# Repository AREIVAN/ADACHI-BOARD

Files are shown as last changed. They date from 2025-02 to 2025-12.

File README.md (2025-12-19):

# ADACHI-BOARD  
### Custom Embedded Control Board for Mini Sumo Robotics  
**ESP32-S3 | PCB Design | Motor Control | Embedded Systems**

---

## 📍 Overview

**ADACHI-BOARD** is a **custom-designed embedded control board** developed for **Mini Sumo robotic applications**, focused on **real-time control**, **compact PCB design**, and **competition-grade reliability**.

This project was created as part of my professional and academic development in **Robotics, Embedded Systems, and Industrial Electronics**, and it is intended to serve as both a **functional robotic platform** and a **technical portfolio project**.

---

## 🎯 Project Objectives

- Design a **compact and robust PCB** for competitive robotics
- Implement **reliable motor control** using discrete drivers
- Apply **best practices in embedded hardware design**
- Demonstrate skills in:
  - PCB design
  - Power regulation
  - Microcontroller integration
  - Robotics-oriented system architecture

---

## ⚙️ System Architecture

- **Main MCU:** ESP32-S3 Mini-1U  
- **Motor Control:** Dual DRV8871 DC motor drivers  
- **Sensors:** Support for up to 10 external sensors  
- **Actuators:** 2 servo outputs  
- **User Interface:** Hardware buttons for strategy selection  
- **Programming Interface:** TTL (UART)  

The board is designed to minimize latency and allow fast response times, which are critical in competitive robotics environments.

---

## 📐 Technical Specifications

| Feature | Description |
|---|---|
| Board Size | 60 mm × 30 mm |
| Max Input Voltage | 24 V |
| MCU | ESP32-S3 Mini-1U |
| Motor Drivers | DRV8871 |
| Voltage Regulation | 5 V / 3.3 V |
| LEDs | SK0605 2427 |
| Programming | UART (TTL) |
| Target Application | Mini Sumo Robot |

---

## 🔘 Hardware Controls

- **RESET** – Microcontroller reset  
- **BOOT** – Programming mode access  
- **STRATEGY 1** – Strategy selection input  
- **STRATEGY 2** – Strategy selection input  

These buttons allow strategy changes without reflashing firmware, improving usability during competitions or testing.

---

## 🧠 Design Considerations

- Compact footprint optimized for Mini Sumo chassis
- Separation of power and logic domains
- Component selection focused on availability and reliability
- Design prepared for iterative improvement and future expansion

---

## 📂 Repository Structure



*(Structure may evolve as the project progresses)*

---

## 🚧 Project Status

- ✔ PCB design completed  
- ✔ Component selection validated  
- 🔄 Firmware development in progress  
- 🔄 Testing and optimization phase  

---

## 🔮 Planned Improvements

- Encoder feedback integration
- Power efficiency optimization
- Enhanced firmware architecture
- Step-by-step replication documentation
- Optional telemetry and data logging

---

## 👨‍💻 About the Author

**Areivan**  
Industrial Robotics Engineering Student  
Industrial Maintenance Technician  

- Experience in embedded systems and PCB design  
- Background in industrial automation and maintenance  
- Focused on robotics, electronics, and applied engineering  

🔗 GitHub: https://github.com/AREIVAN

---

## 📜 License & Usage

This project is intended for **educational and experimental purposes**.  
You may reference or reuse the design with proper credit to the author.

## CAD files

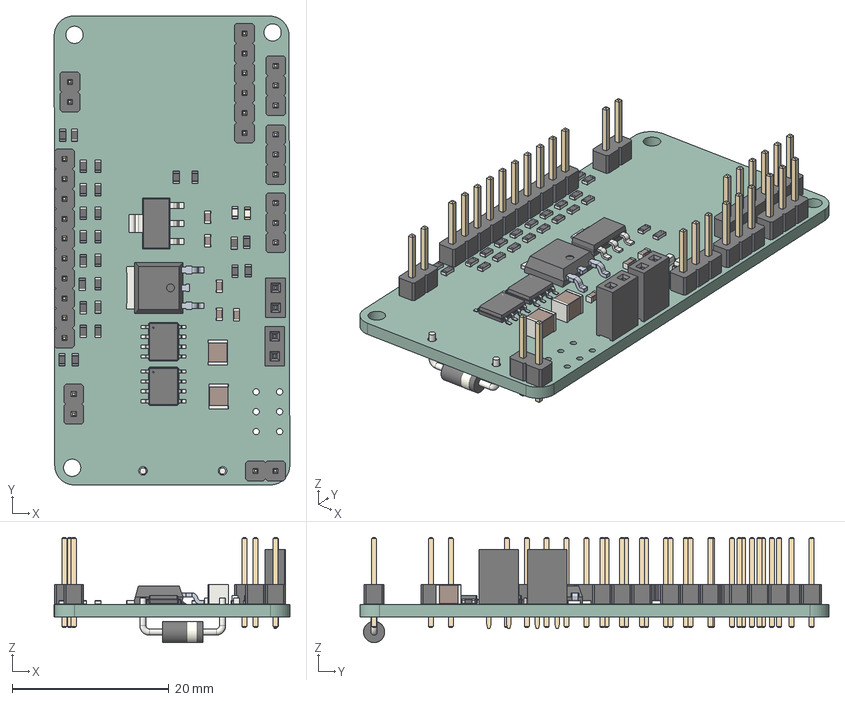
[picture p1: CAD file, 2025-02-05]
ADACHI/ADACHI.step
30.1 x 59.9 x 13.4 mm
PinHeader_1x06_P254mm_Vertical
R_0603_1608Metric x 26
C_0603_1608Metric x 5
PinHeader_1x02_P254mm_Vertical x 3
CQ assembly
PinHeader_1x03_P254mm_Vertical x 3
PinHeader_1x10_P254mm_Vertical
LED_0603_1608Metric x 2
C_1210_3225Metric x 2
PinSocket_1x02_P254mm_Vertical x 2
Texas_HTSOP_8_1EP_39x49mm_P127mm_EP285x49mm_Mask24x31mm_ThermalVias x 2
SOT_223
D_DO-41_SOD81_P10.16mm_Horizontal
ADACHI_PCB

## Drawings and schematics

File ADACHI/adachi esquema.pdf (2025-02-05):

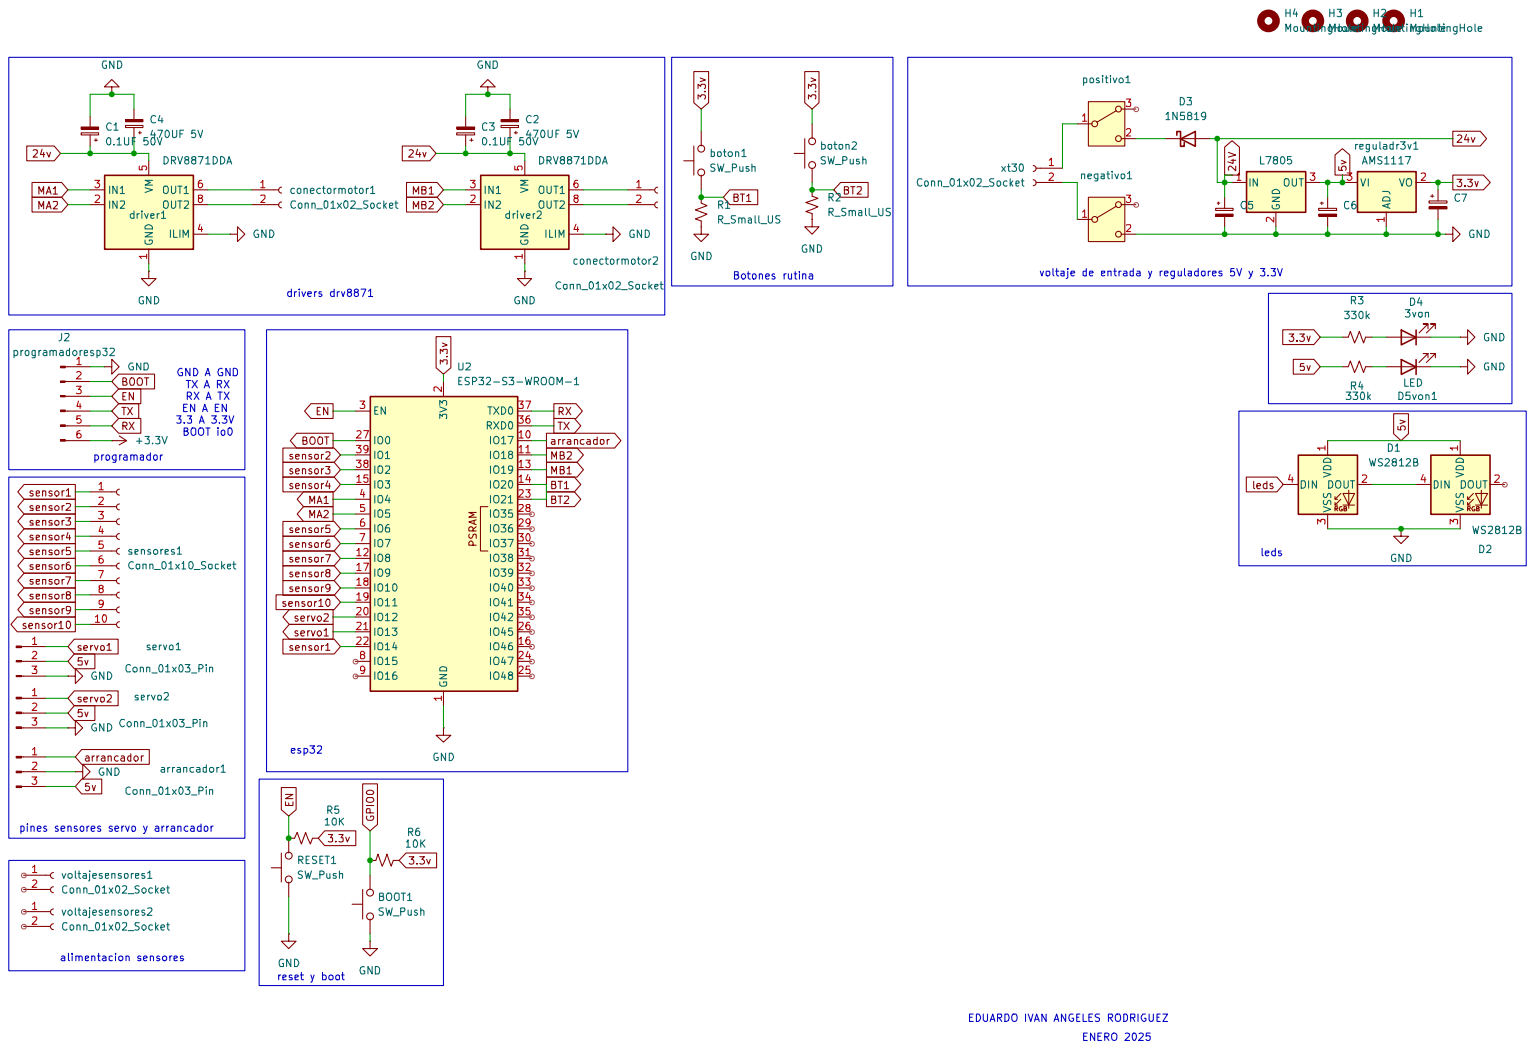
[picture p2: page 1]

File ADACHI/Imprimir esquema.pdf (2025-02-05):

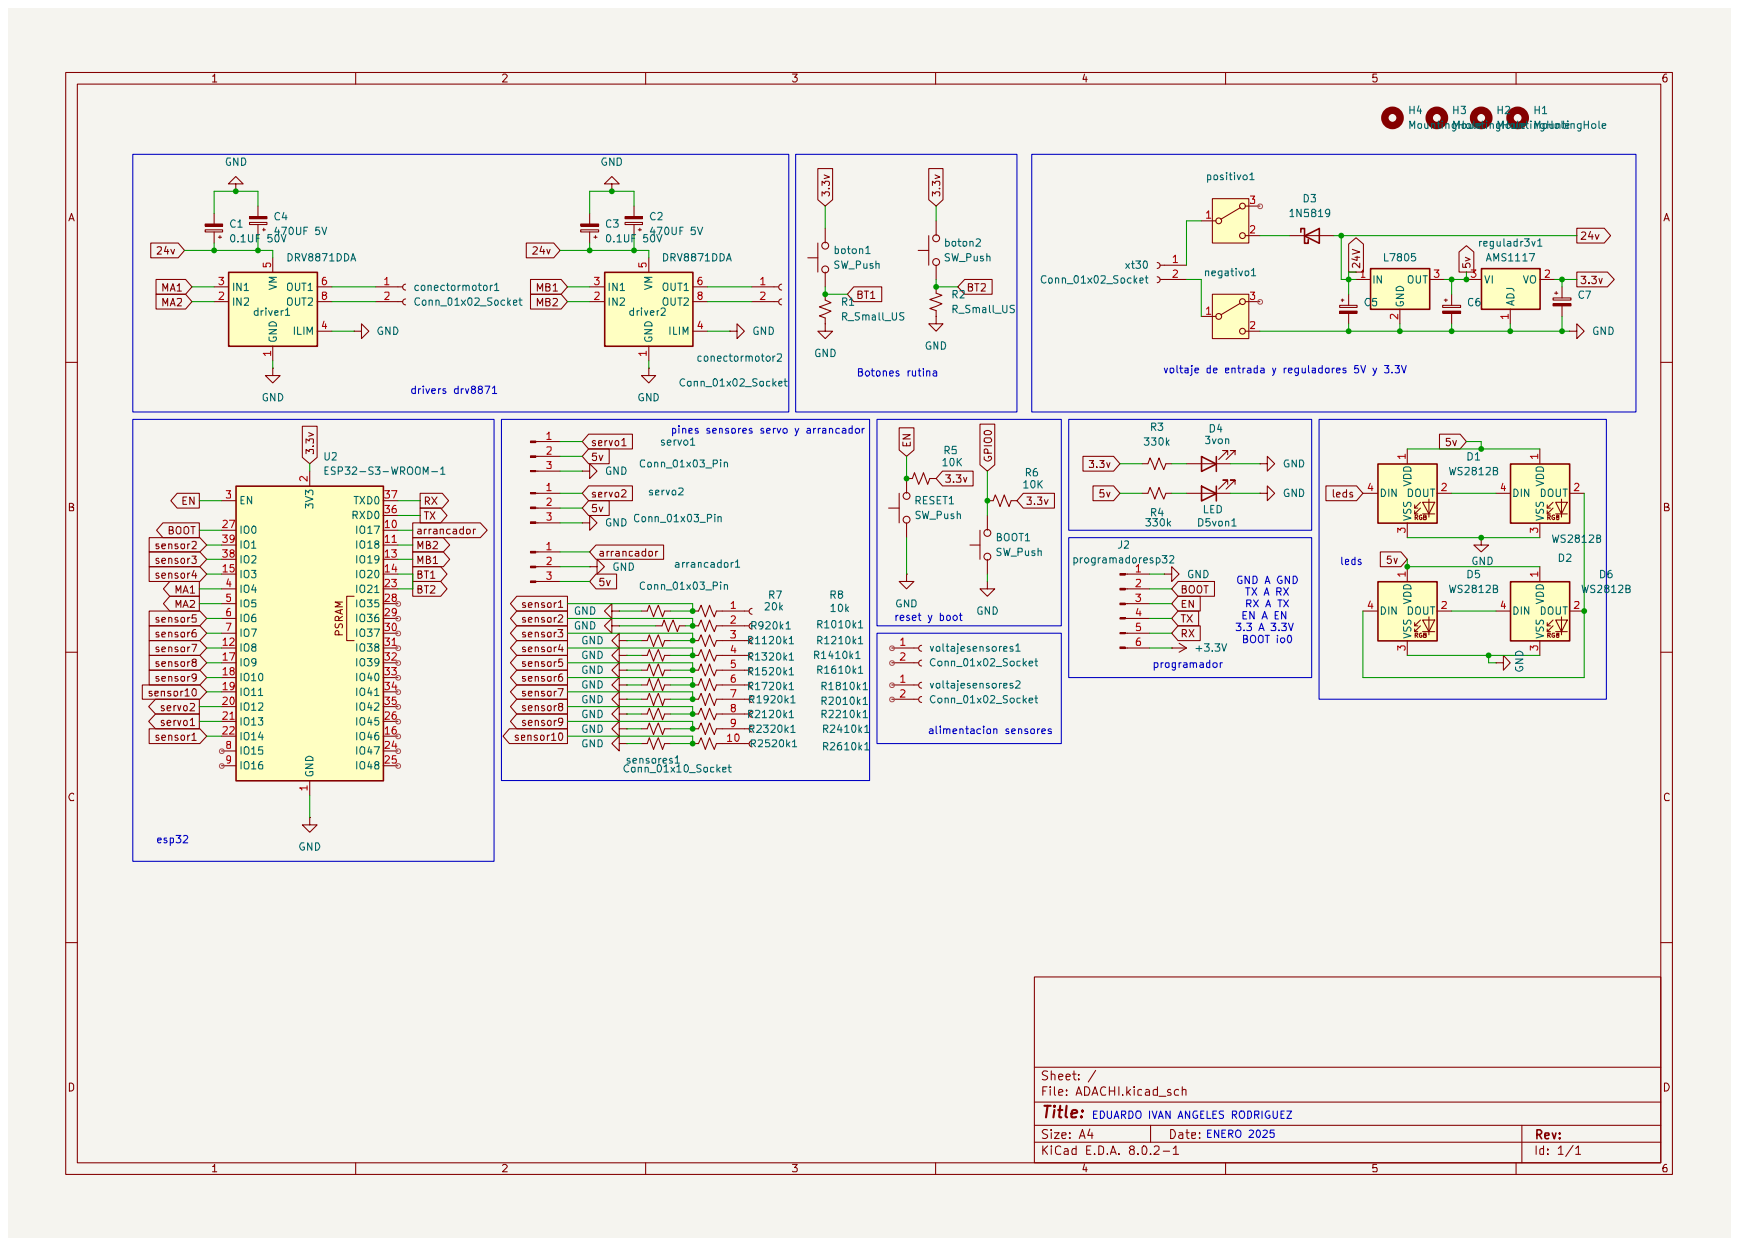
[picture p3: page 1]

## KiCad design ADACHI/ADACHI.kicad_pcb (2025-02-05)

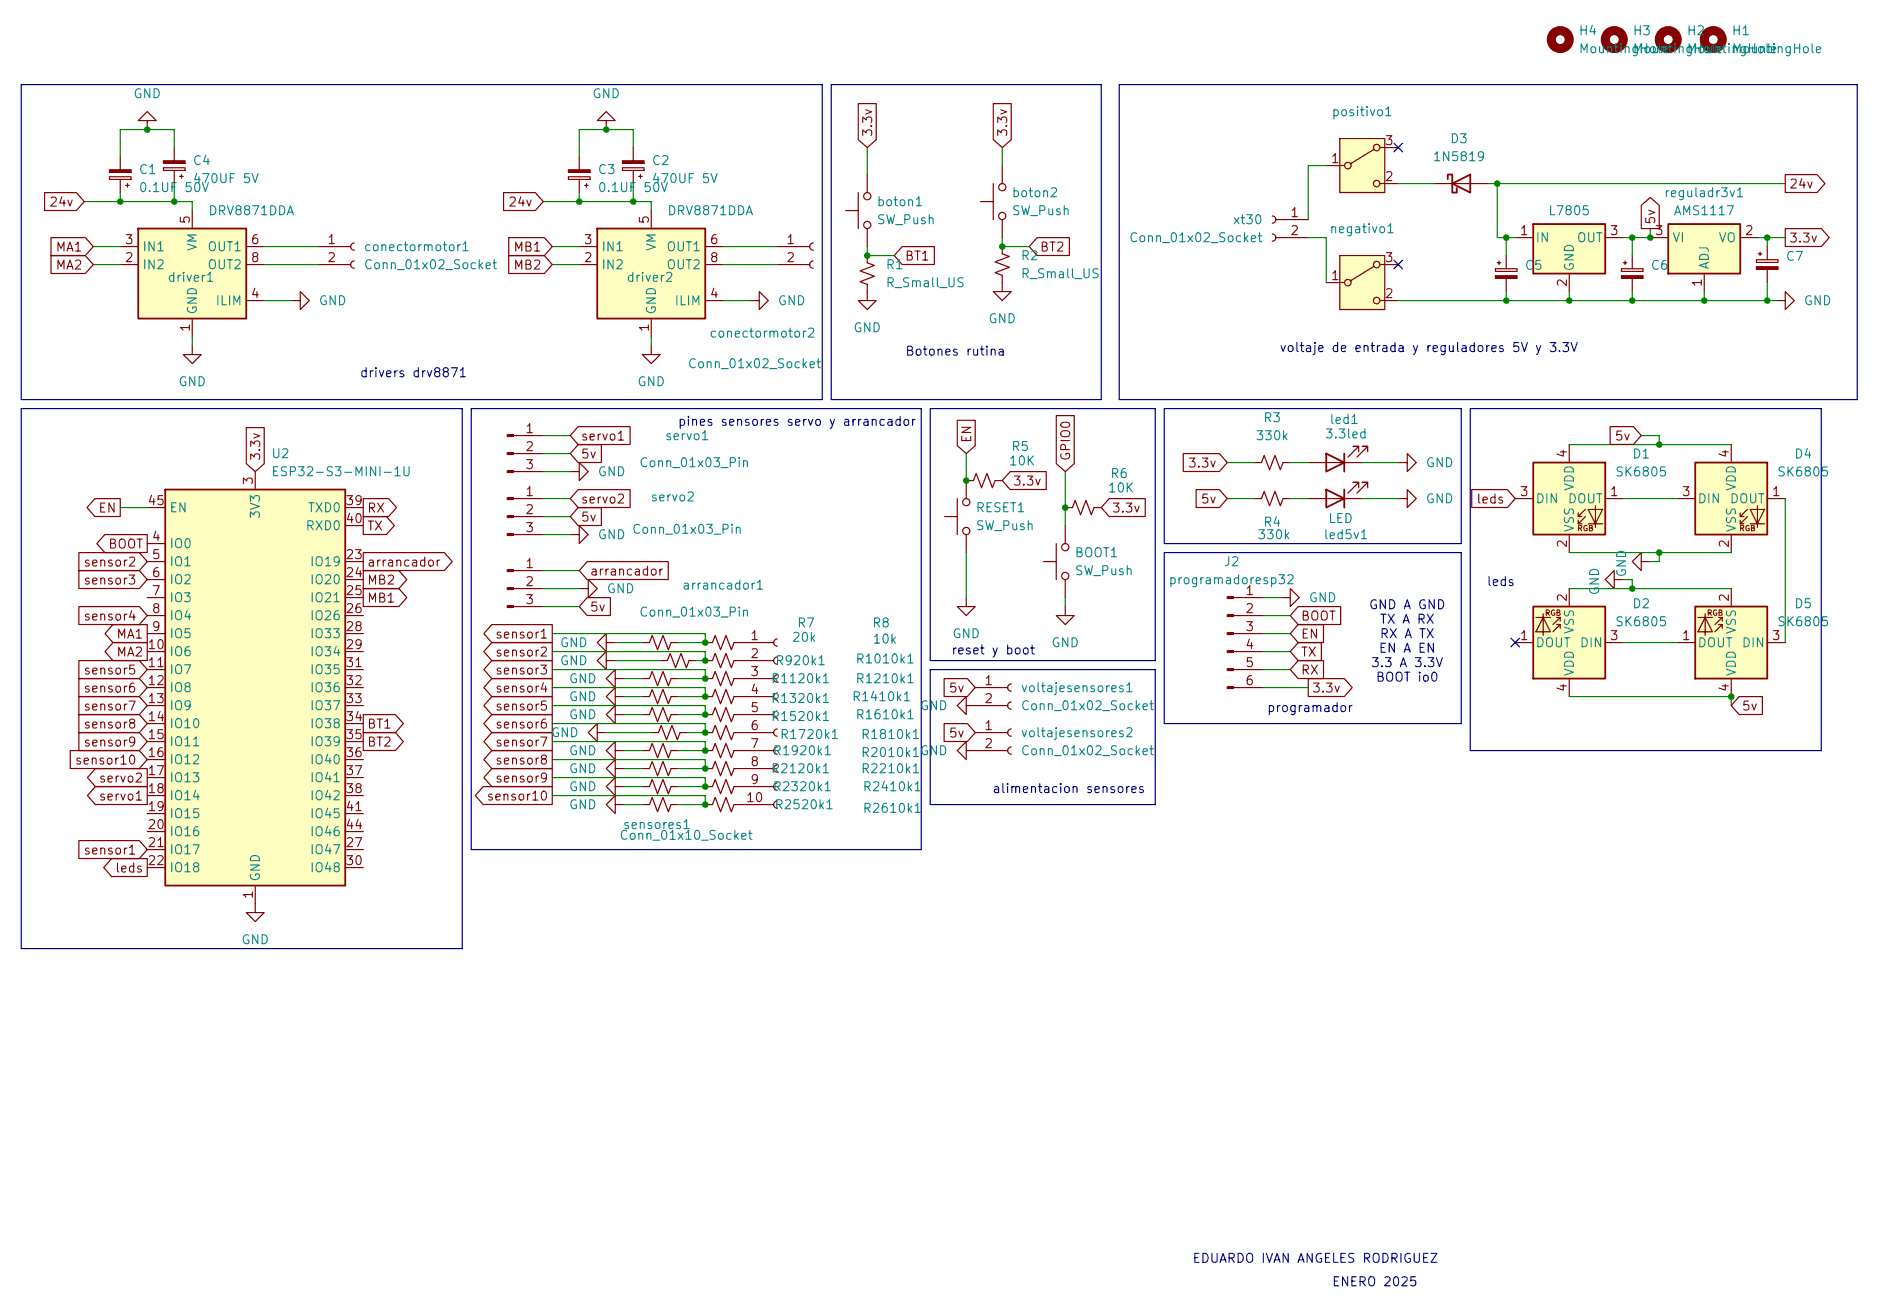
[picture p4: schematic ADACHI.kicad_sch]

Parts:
BOOT1: SW_Push; SW_Push_1P1T_NO_Vertical_Wuerth_434133025816
C1, C3: 0.1UF 50V; C_0603_1608Metric
C2, C4: 470UF 5V; C_1210_3225Metric
C5, C6, C7: C_0603_1608Metric
D1, D2, D4, D5: SK6805; LED_SK6805_PLCC4_2.4x2.7mm_P1.3mm
D3: 1N5819; D_DO-41_SOD81_P10.16mm_Horizontal
H1, H3, H4: MountingHole; MountingHole_2.2mm_M2_ISO7380_Pad_TopBottom
H2: MountingHole; MountingHole_2.2mm_M2_ISO14580_Pad_TopBottom
J2: programadoresp32; PinHeader_1x06_P2.54mm_Vertical
R1, R2: R_Small_US; R_0603_1608Metric
R3, R4: 330k; R_0603_1608Metric
R5, R6: 10K; R_0603_1608Metric
R7: 20k; R_0603_1608Metric
R8: 10k; R_0603_1608Metric
R920k1, R1010k1, R1120k1, R1210k1, R1320k1, R1410k1, R1520k1, R1610k1, R1720k1, R1810k1, R1920k1, R2010k1, R2120k1, R2210k1, R2320k1, R2410k1, R2520k1, R2610k1: R_0603_1608Metric
RESET1: SW_Push; SW_Push_1P1T_NO_Vertical_Wuerth_434133025816
U1: L7805; TO-252-2
U2: ESP32-S3-MINI-1U; ESP32-S2-MINI-1U
arrancador1: Conn_01x03_Pin; PinHeader_1x03_P2.54mm_Vertical
boton1, boton2: SW_Push; SW_Push_1P1T_NO_Vertical_Wuerth_434133025816
conectormotor1, conectormotor2: Conn_01x02_Socket; PinSocket_1x02_P2.54mm_Vertical
driver1, driver2: DRV8871DDA; Texas_HTSOP-8-1EP_3.9x4.9mm_P1.27mm_EP2.95x4.9mm_Mask2.4x3.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
led1: 3.3led; LED_0603_1608Metric
led5v1: LED; LED_0603_1608Metric
negativo1: SW_Slide-03_Wuerth-WS-SLTV_10x2.5x6.4_P2.54mm
positivo1: SW_Slide-03_Wuerth-WS-SLTV_10x2.5x6.4_P2.54mm
reguladr3v1: AMS1117; SOT-223-3_TabPin2
sensores1: Conn_01x10_Socket; PinHeader_1x10_P2.54mm_Vertical
servo1, servo2: Conn_01x03_Pin; PinHeader_1x03_P2.54mm_Vertical
voltajesensores1, voltajesensores2: Conn_01x02_Socket; PinHeader_1x02_P2.54mm_Vertical
xt30: Conn_01x02_Socket; PinHeader_1x02_P2.54mm_Vertical

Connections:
3.3v: C7.1, J2.6, R3.1, R5.2, R6.2, U2.3 (3V3), boton1.2, boton2.2, reguladr3v1.2 (VO)
5v: C6.1, D1.4 (VDD), D2.4 (VDD), D4.4 (VDD), D5.4 (VDD), R4.1, U1.3 (OUT), arrancador1.3, reguladr3v1.3 (VI), servo1.2, servo2.2, voltajesensores1.1, voltajesensores2.1
24v: C1.1, C2.1, C3.1, C4.1, C5.1, D3.2 (A), U1.1 (IN), driver1.5 (VM), driver2.5 (VM)
BOOT: J2.2, U2.4 (IO0)
BT1: R1.1, U2.34 (IO38), boton1.1
BT2: R2.1, U2.35 (IO39), boton2.1
EN: J2.3, R5.1, RESET1.2, U2.45 (EN)
GND: BOOT1.1, C1.2, C2.2, C3.2, C4.2, C5.2, C6.2, C7.2, D1.2 (VSS), D2.2 (VSS), D4.2 (VSS), D5.2 (VSS), J2.1, R1.2, R2.2, R7.2, R920k1.2, R1120k1.2, R1320k1.2, R1520k1.2, R1720k1.2, R1920k1.2, R2120k1.2, R2320k1.2, R2520k1.2, RESET1.1, U1.2 (GND), U2.1 (GND), U2.2 (GND), U2.42 (GND), U2.43 (GND), U2.46 (GND), U2.47 (GND), U2.48 (GND), U2.49 (GND), U2.50 (GND), U2.51 (GND), U2.52 (GND), U2.53 (GND), U2.54 (GND), U2.55 (GND), U2.56 (GND), U2.57 (GND), U2.58 (GND), U2.59 (GND), U2.60 (GND), U2.61 (GND), U2.62 (GND), U2.63 (GND), U2.64 (GND), U2.65 (GND), arrancador1.2, driver1.1 (GND), driver1.4 (ILIM), driver1.7 (GND), driver1.9 (GND), driver2.1 (GND), driver2.4 (ILIM), driver2.7 (GND), driver2.9 (GND), led1.1 (K), led5v1.1 (K), negativo1.2 (C), reguladr3v1.1 (ADJ), servo1.3, servo2.3, voltajesensores1.2, voltajesensores2.2
GPIO0: BOOT1.2, R6.1
MA1: U2.9 (IO5), driver1.3 (IN1)
MA2: U2.10 (IO6), driver1.2 (IN2)
MB1: U2.25 (IO21), driver2.3 (IN1)
MB2: U2.24 (IO20), driver2.2 (IN2)
unnamed: D1.1 (DOUT), D4.3 (DIN)
unnamed: D2.3 (DIN), D5.1 (DOUT)
unnamed: D3.1 (K), positivo1.2 (C)
unnamed: D4.1 (DOUT), D5.3 (DIN)
unnamed: conectormotor1.1, driver1.6 (OUT1)
unnamed: conectormotor1.2, driver1.8 (OUT2)
unnamed: conectormotor2.1, driver2.6 (OUT1)
unnamed: conectormotor2.2, driver2.8 (OUT2)
unnamed: R3.2, led1.2 (A)
unnamed: R4.2, led5v1.2 (A)
unnamed: negativo1.1 (B), xt30.2
unnamed: positivo1.1 (B), xt30.1
unnamed: R8.1, sensores1.1
unnamed: R1010k1.1, sensores1.2
unnamed: R1210k1.1, sensores1.3
unnamed: R1410k1.1, sensores1.4
unnamed: R1610k1.1, sensores1.5
unnamed: R1810k1.1, sensores1.6
unnamed: R2010k1.1, sensores1.7
unnamed: R2210k1.1, sensores1.8
unnamed: R2410k1.1, sensores1.9
unnamed: R2610k1.1, sensores1.10
RX: J2.5, U2.39 (TXD0)
TX: J2.4, U2.40 (RXD0)
arrancador: U2.23 (IO19), arrancador1.1
leds: D1.3 (DIN), U2.22 (IO18)
sensor1: R7.1, R8.2, U2.21 (IO17)
sensor2: R920k1.1, R1010k1.2, U2.5 (IO1)
sensor3: R1120k1.1, R1210k1.2, U2.6 (IO2)
sensor4: R1320k1.1, R1410k1.2, U2.8 (IO4)
sensor5: R1520k1.1, R1610k1.2, U2.11 (IO7)
sensor6: R1720k1.1, R1810k1.2, U2.12 (IO8)
sensor7: R1920k1.1, R2010k1.2, U2.13 (IO9)
sensor8: R2120k1.1, R2210k1.2, U2.14 (IO10)
sensor9: R2320k1.1, R2410k1.2, U2.15 (IO11)
sensor10: R2520k1.1, R2610k1.2, U2.16 (IO12)
servo1: U2.18 (IO14), servo1.1
servo2: U2.17 (IO13), servo2.1

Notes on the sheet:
reset y boot
pines sensores servo y arrancador
drivers drv8871
Botones rutina
ENERO 2025
programador
alimentacion sensores
GND A GND TX A RX RX A TX EN A EN 3.3 A 3.3V BOOT io0
leds
EDUARDO IVAN ANGELES RODRIGUEZ
voltaje de entrada y reguladores 5V y 3.3V

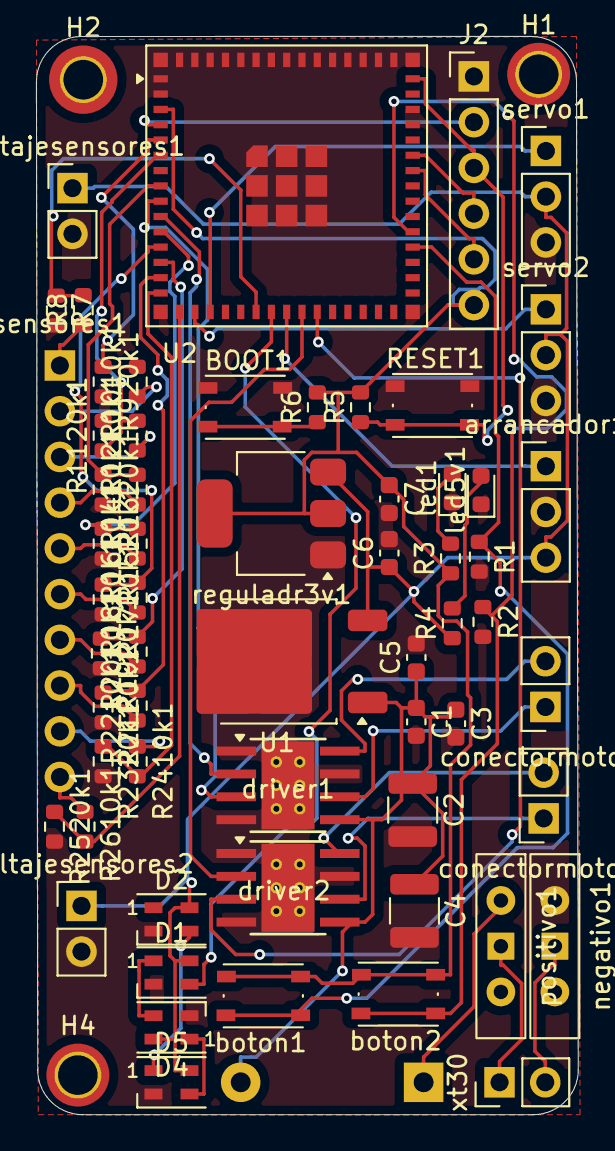
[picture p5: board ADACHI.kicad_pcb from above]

Board: 2 copper layers, 30.1 x 59.9 mm, 64 parts (1 on the bottom side), 51 nets.

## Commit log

2025-01-31 Add files via upload
    el esquematico y el 3d parecen correctos, falta enrutar
2025-02-01 Add files via upload
    primer enrutamiento terminado, falta checar si todas las conexiones son correctas y corregir el grosor de pistas donde hay mayor voltaje
2025-02-05 archivos kicad
    version final de la placa
    [ADACHI-B_Cu.gbr, ADACHI-B_Mask.gbr, ADACHI-B_Paste.gbr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]
